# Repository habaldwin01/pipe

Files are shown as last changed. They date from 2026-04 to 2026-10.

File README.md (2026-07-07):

# Particle Imager for Plankton in the Environment

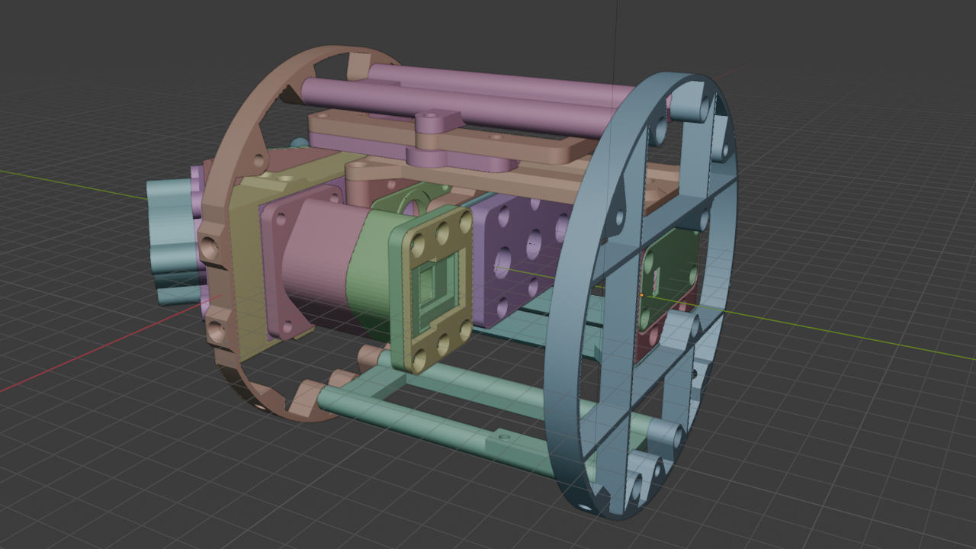
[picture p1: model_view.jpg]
View of the printable parts of PIPE in Blender


The PIPE is an almost fully 3D-printable pumped fluid microscope targeting particles in the range of 10-500 micron. As designed, it requires ***zero*** specialist components, with everything being either 3D-printable, readily avalaible to purchase on sites like eBay, or quickly made with a hacksaw and drill.

**Side-by-side comparison of the resolution of a PIPE prototype vs the IFCB:**

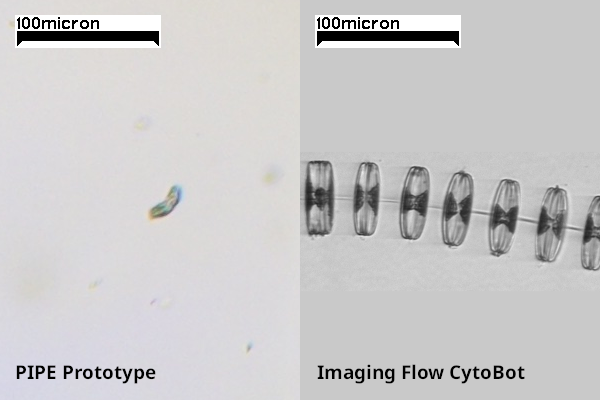
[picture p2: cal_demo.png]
Example side-by-side comparison of the resolution of the PIPE vs the IFCB


## Licence and acknowledgements

This project would not have been possible without the work of the team at FairScope, creators of the [PlanktoScope](https://github.com/fairscope/PlanktoScope). The PIPE is heavily inspired by the PlanktoScope, and borrows some pieces of its design. All physical designs for the PIPE are therefore also CERN OHL-S V2 licensed, and you are free to adapt and re-use the designs in accordance with the licence.

## Non-printable parts required

- 2x 8mm ID, 14mm OD, 0.5mm thick washer (stainless steel preferably, although copper crush washers also work)
- ~50 M3 16mm countersunk hex bolts
- ~50 M3 4-6mm brass threaded inserts
- 2x 6x2mm o-ring
- 1x 12x2mm o-ring
- 2x 10x2mm o-ring
- 1x 38x3mm o-ring
- 4x Female Luer Lock to 2.4mm silicone tube ID fittings
- 4x Male Luer Lock to 2.4mm silicone tube ID fittings
- About 1m 2mm ID silicone tube
- Standard microscope slide (75x26x1mm)
- 2x 25mm diameter CO2 laser cutter Molybdenum mirrors
- Piece (75x26x2mm) of clear acrylic or polycarbonate with two 5mm holes drilled 50mm apart, centered
- Single segment (10-30mm) of 12v white LED strip
- Peristaltic pump with 2mm silicone tube fittings
- Standard optical microscope condenser
- Standard Plan 10/0.25 Objective with RMS thread (must NOT be infinity-corrected)
- Raspberry Pi 3 B+ (or Later) and power supply
- Raspberry Pi Camera Module 3
- 12V 2A power supply
- 2x step-down DC-DC converters 12V input 5V 2A(minimum) output

## Notes on printing

All components have been printed successfully on a stock Creality Ender 3. For most pieces, the default print settings are 0.4mm layer heights with the "SUPERDRAFT" speed preset in Prusa Slicer. The only exceptions are:

- slide/optical_stage_slide_oring_guide
- optical_stage/objective_mount

These parts in particular were printed with 0.2mm layer heights on the "NORMAL" preset.

Tolerances are built in to most designs, and will be suitable for most consumer 3D printers, but if you need to change them, look for a variable called "slop_adjust" near the top of the OpenSCAD file. This is used to set the gap between various surfaces that are meant to connect or brush past each other.

### Photo of an early prototype of the PIPE

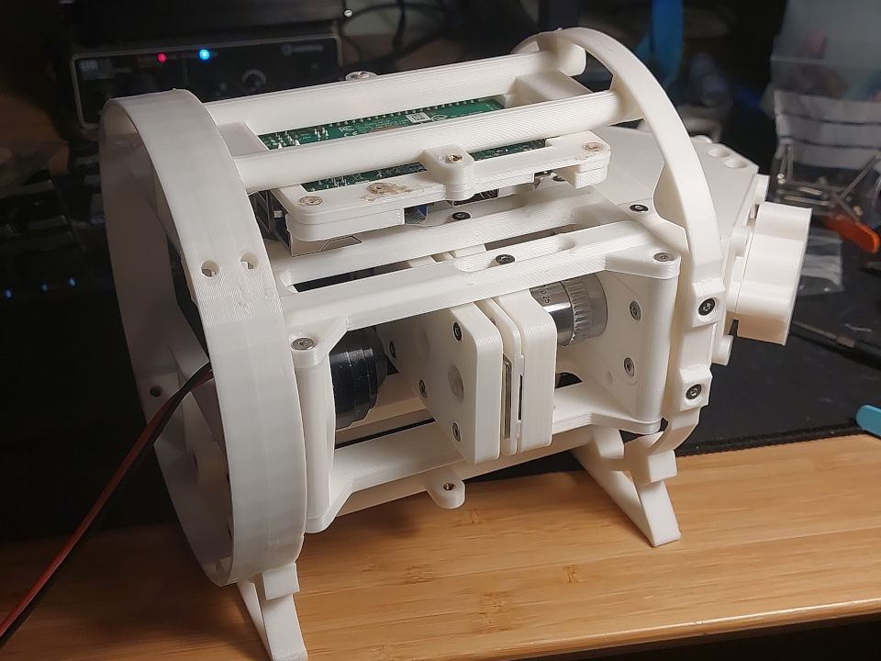
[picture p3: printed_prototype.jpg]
Early prototype of the PIPE


## Why is it called PIPE?

Because it fits in one! The entire design is built to fit in a 150mm ID pipe so it can be sealed within a pressure housing. While there aren't designs for a pressure housing included here, 150mm was chosen as it's also relatively easy to find [150mm ID PVC ducting](https://www.screwfix.com/p/manrose-150mm-round-ducting-1m/207gy). If you're not in need of serious depth rating, this will do the job of keeping the device dry.

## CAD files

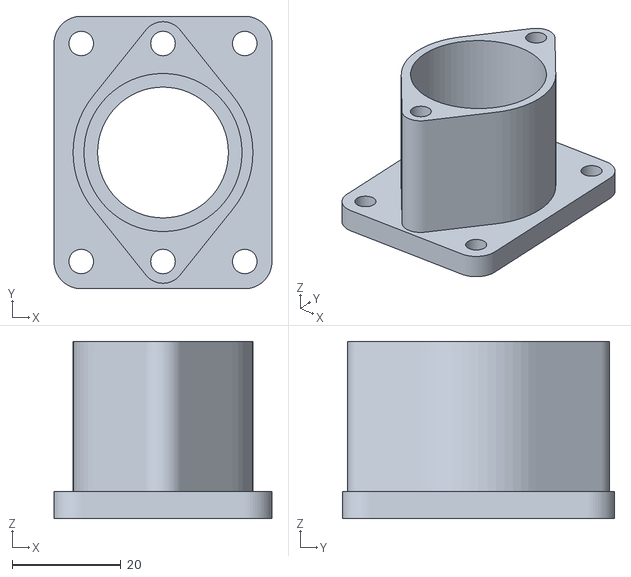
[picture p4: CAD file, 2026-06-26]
models/camera_stage/eyepiece_mount_main.stl
40.0 x 50.0 x 32.5

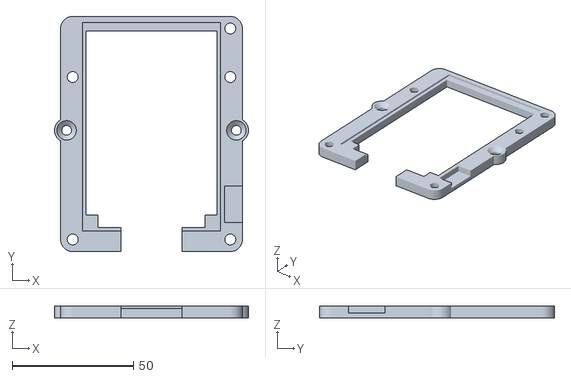
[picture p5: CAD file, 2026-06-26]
models/electronics/rpi_mount/rpi_mount_main.stl
80.0 x 97.0 x 5.00

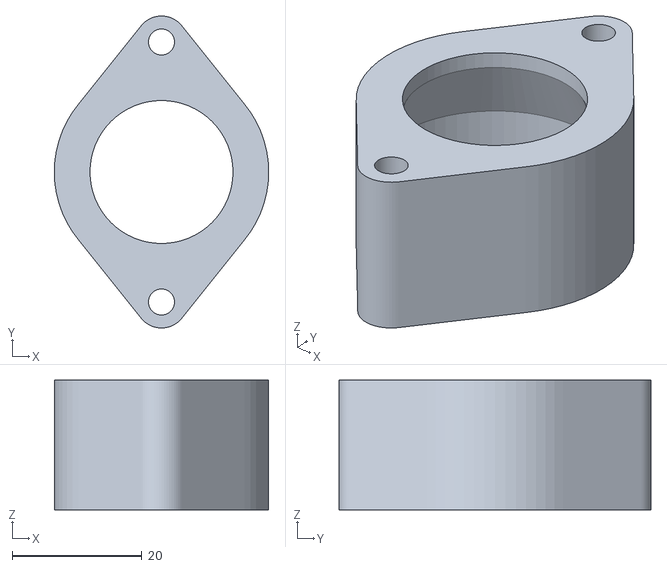
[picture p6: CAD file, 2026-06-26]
models/camera_stage/eyepiece_mount_spacer.stl
33.0 x 48.0 x 20.0

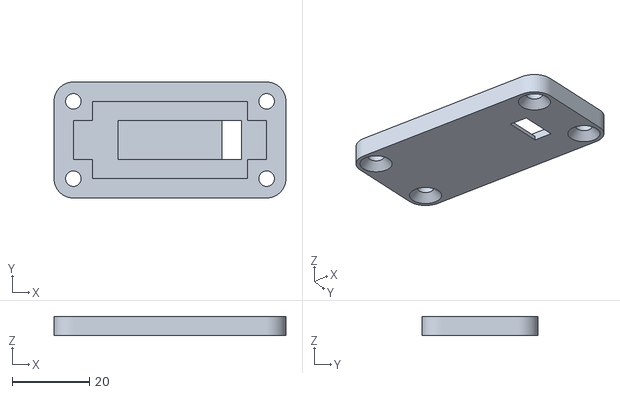
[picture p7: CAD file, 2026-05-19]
models/electronics/lamp_mount/lamp_mount.stl
60.0 x 30.0 x 5.00

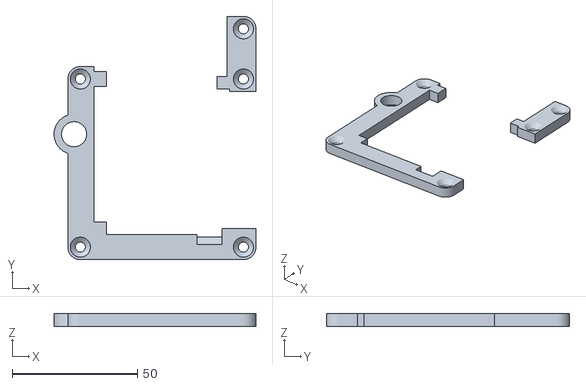
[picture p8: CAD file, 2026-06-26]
models/electronics/rpi_mount/rpi_mount_clamp.stl
80.5 x 97.0 x 5.00

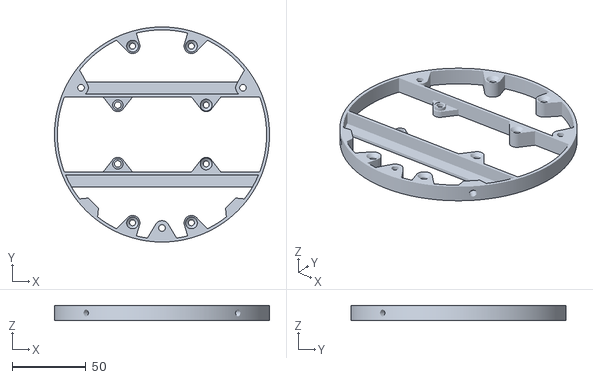
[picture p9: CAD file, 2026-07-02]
models/frame/front_frame.stl
146.0 x 146.0 x 10.0

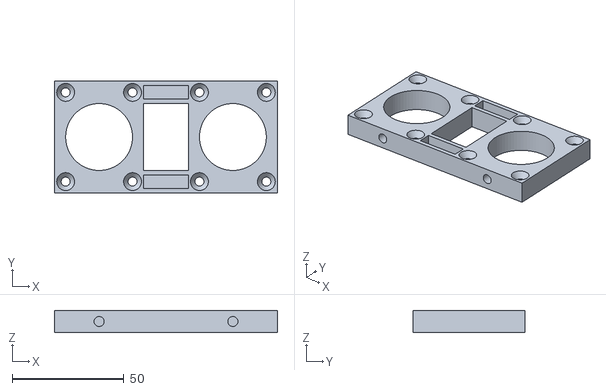
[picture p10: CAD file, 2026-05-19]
models/mirror_stage/mirror_stage_flange_plate.stl
100.0 x 50.0 x 10.0

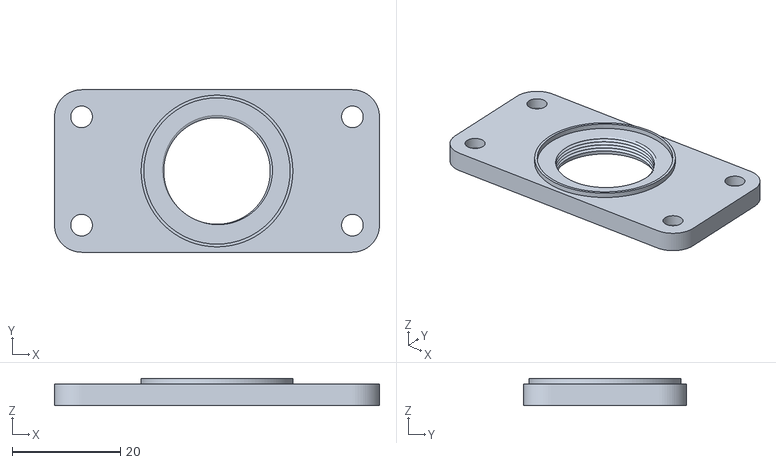
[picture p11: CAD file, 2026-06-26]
models/optical_stage/objective_mount.stl
60.0 x 30.0 x 5.00

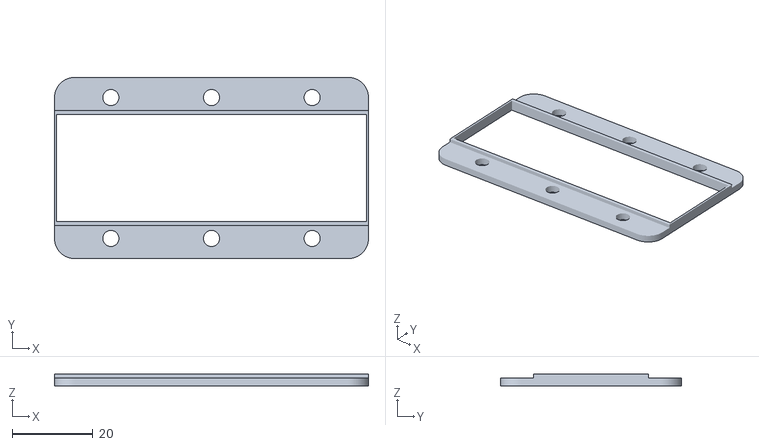
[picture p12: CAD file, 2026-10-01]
models/slide/optical_stage_slide_back_guide.stl
78.0 x 45.0 x 3.00

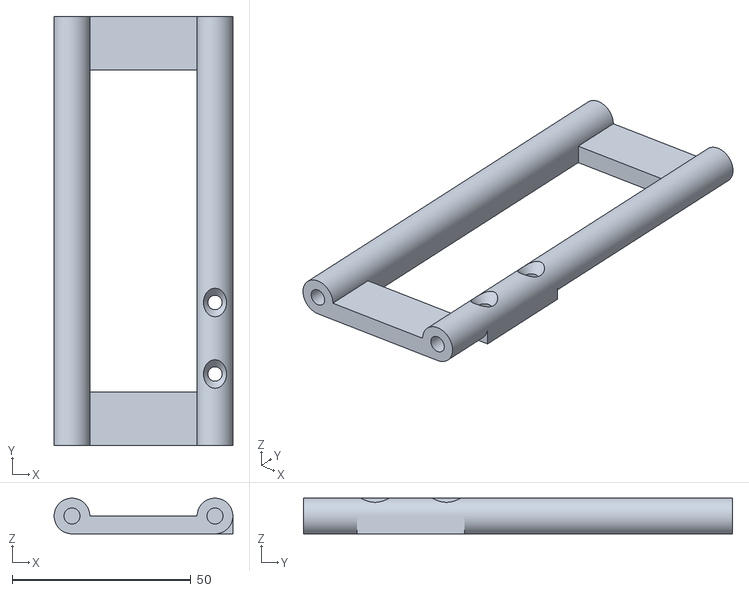
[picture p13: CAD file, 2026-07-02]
models/frame/bottom_frame.stl
50.0 x 120.0 x 10.00

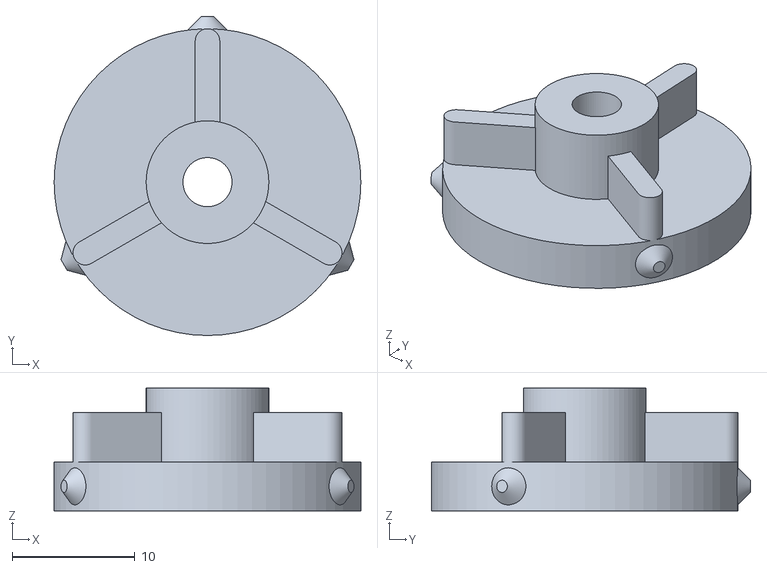
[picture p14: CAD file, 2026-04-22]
models/mirror_stage/cap_lid.stl
25.0 x 26.0 x 10.0

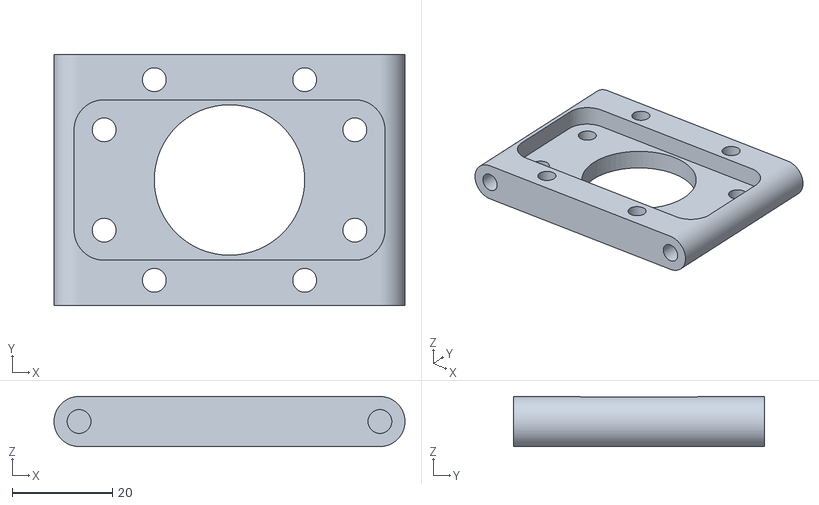
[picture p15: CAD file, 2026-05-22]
models/optical_stage/optical_cage_objective_side.stl
70.0 x 50.0 x 10.0

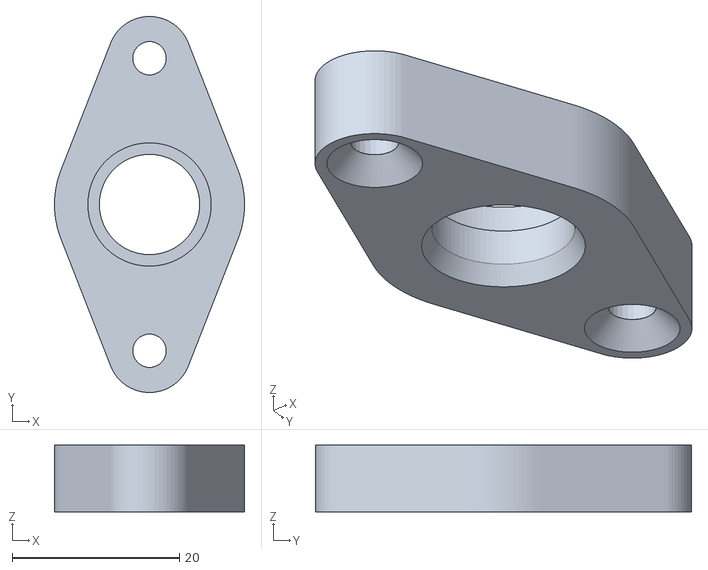
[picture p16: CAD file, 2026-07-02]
models/slide/optical_stage_slide_luer_clamp.stl
22.7 x 45.0 x 8.00

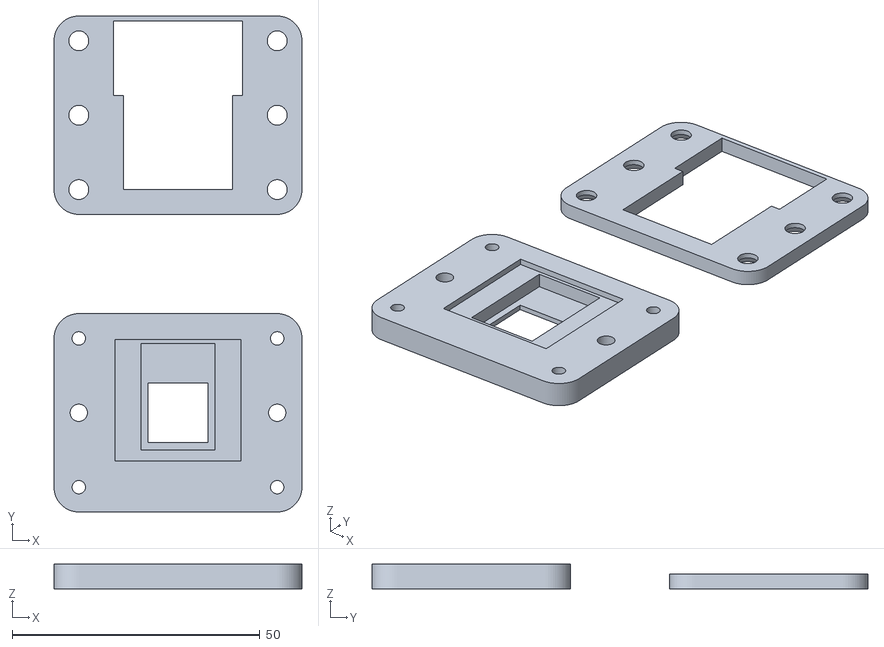
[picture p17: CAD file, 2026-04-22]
models/electronics/rpi_mount/rpi_camera_module_mount.stl
50.0 x 100.0 x 5.00

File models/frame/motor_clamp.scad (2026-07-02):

$fa=1;
$fs=0.5;

frame_length = 120;

sh_through = 4;
sh_countersink = 3;
sh_thread = 4.5; // 2.7 for tapping, 4.5 for brass insert

motor_dia = 32;

shell_thickness = 2;

motor_center_height = 40;

module countersink_cyl() {
    hull () {
        translate([0,0,-30])cylinder(1, (sh_countersink-1) + (sh_through/2), (sh_countersink-1) + (sh_through/2));
        translate([0,0,-1])cylinder(sh_countersink, (sh_countersink-1) + (sh_through/2), sh_through/2);
    }

    translate([0,0,0])cylinder(30, sh_through/2, sh_through/2);
}

difference() {
    union(){
        cylinder(10,motor_dia/2 + shell_thickness,motor_dia/2 + shell_thickness);
        translate([0,-10/2 + 10,0])cube([motor_center_height,10,10]);
        translate([0,-10/2 - 10,0])cube([motor_center_height,10,10]);
        translate([motor_center_height-shell_thickness,-30/2,0])cube([shell_thickness,30,10]);
        
        difference(){
            translate([-motor_dia/2-10,-2.5-5,0])cube([10,5,10]);
            translate([-motor_dia/2-5,-7,5])rotate([-90,0,0])countersink_cyl();
        }
        difference(){
            translate([-motor_dia/2-10,2.5,0])cube([10,5,10]);
            translate([-motor_dia/2-5,0,5])rotate([-90,0,0])cylinder(50,sh_thread/2,sh_thread/2);
        }
        
    }

    translate([0,0,-1])cylinder(12,motor_dia/2,motor_dia/2);
    
    translate([-50,-2.5,-1])cube([50,5,12]);
    
    translate([motor_center_height-20,-(20/2),5])rotate([0,90,0])cylinder(50,sh_thread/2,sh_thread/2);
    translate([motor_center_height-20,+(20/2),5])rotate([0,90,0])cylinder(50,sh_thread/2,sh_thread/2);
}

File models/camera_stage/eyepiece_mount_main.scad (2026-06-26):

use <threadlib/threadlib.scad>
$fn=64;


sh_through = 4;
sh_countersink = 3;
sh_thread = 4.5; // 2.7 for tapping, 4.5 for brass insert


shoulder_size = 2;
thickness = 5;
wall_thickness = 2;

through_casing_radius = sh_through/2 + wall_thickness;

mounting_holes_height = 30;
mounting_holes_width = 40;

difference() {
    union() {
        hull() {
            translate([0,-20,0])cylinder(31.5+shoulder_size-1, through_casing_radius,through_casing_radius);
            translate([0,0,0])cylinder(31.5+shoulder_size-1, 29/2 + 2, 29/2 + 2);
            translate([0,20,0])cylinder(31.5+shoulder_size-1, through_casing_radius,through_casing_radius);
        }
        hull() {
            translate([-mounting_holes_height/2,mounting_holes_width/2,0])cylinder(thickness,5,5);
            translate([mounting_holes_height/2,mounting_holes_width/2,0])cylinder(thickness,5,5);
            translate([-mounting_holes_height/2,-mounting_holes_width/2,0])cylinder(thickness,5,5);
            translate([mounting_holes_height/2,-mounting_holes_width/2,0])cylinder(thickness,5,5);
        }
    }
    
    translate([0,0,shoulder_size])cylinder(31.5+1,29/2,29/2);
    translate([0,0,-1])cylinder(10,24/2,24/2);
    
    
    translate([0,-20,-1])cylinder(50, sh_thread/2, sh_thread/2);
    translate([0,20,-1])cylinder(50, sh_thread/2, sh_thread/2);
    
    translate([-mounting_holes_height/2,mounting_holes_width/2,-1])cylinder(15, sh_thread/2, sh_thread/2);
    translate([mounting_holes_height/2,mounting_holes_width/2,-1])cylinder(15, sh_thread/2, sh_thread/2);
    translate([-mounting_holes_height/2,-mounting_holes_width/2,-1])cylinder(15, sh_thread/2, sh_thread/2);
    translate([mounting_holes_height/2,-mounting_holes_width/2,-1])cylinder(15, sh_thread/2, sh_thread/2);
}

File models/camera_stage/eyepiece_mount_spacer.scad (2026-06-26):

use <threadlib/threadlib.scad>
$fn=64;


sh_through = 4;
sh_countersink = 3;
sh_thread = 4.5; // 2.7 for tapping, 4.5 for brass insert

shoulder_size = 2;
thickness = 10;
wall_thickness = 2;

through_casing_radius = sh_through/2 + wall_thickness;

mounting_holes_height = 30;
mounting_holes_width = 40;

eyepiece_distance = 20;

difference() {
    union() {
        hull() {
            translate([0,-20,0])cylinder(eyepiece_distance, through_casing_radius,through_casing_radius);
            translate([0,0,0])cylinder(eyepiece_distance, 29/2 + 2, 29/2 + 2);
            translate([0,20,0])cylinder(eyepiece_distance, through_casing_radius,through_casing_radius);
        }
    }
    
    translate([0,0,-shoulder_size-8])cylinder(eyepiece_distance,29/2,29/2);
    translate([0,0,eyepiece_distance-shoulder_size-8])cylinder(8,29/2,22/2);
    translate([0,0,-1])cylinder(eyepiece_distance+2,22/2,22/2);
    
    translate([0,-20,-1])cylinder(50, sh_through/2, sh_through/2);
    translate([0,20,-1])cylinder(50, sh_through/2, sh_through/2);
}

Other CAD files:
models/frame/motor_clamp.stl
models/mirror_stage/static_mirror_bracket.stl
models/optical_stage/optical_cage_side.stl
models/slide/optical_stage_slide_centre_clamp.stl
models/frame/back_frame.scad
models/electronics/lamp_mount/lamp_mount.scad
models/electronics/rpi_mount/rpi_camera_module_mount.scad
models/electronics/rpi_mount/rpi_mount.scad
models/electronics/rpi_mount/rpi_mount_clamp.scad
models/electronics/rpi_mount/rpi_mount_main.scad
models/frame/back_frame.stl
models/frame/bottom_frame.scad
models/frame/front_frame.scad
models/frame/mirror_flange_carrier.scad
models/frame/mirror_flange_carrier.stl
models/frame/open_frame_feet.scad
models/frame/open_frame_feet.stl
models/frame/top_frame.scad
models/frame/top_frame.stl
models/mirror_stage/cap_base.scad
models/mirror_stage/cap_base.stl
models/mirror_stage/cap_lid.scad
models/mirror_stage/mirror_stage_body.scad
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

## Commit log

2026-04-22 Initial work
    [cap_base.scad, cap_base.stl, cap_lid.scad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]
2026-05-19 General design refinements
    [condenser_side_frame.scad, lamp_mount.scad, lamp_mount.stl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]
2026-05-20 Improvements to frame
    [back_frame.scad, condenser_side_frame.scad, front_frame.scad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]
2026-05-22 General improvements and frame design
    [back_frame.stl, bottom_frame.scad, bottom_frame.stl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]
2026-05-24 Updates to slide design
    [objective_mount.scad, objective_mount.stl, optical_cage_objective_side.scad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]
2026-06-26 Design optimisations and more clearance for slide
    [eyepiece_mount_main.scad, eyepiece_mount_main.stl, eyepiece_mount_spacer.scad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]
2026-06-30 Significant frame improvements
    [back_frame.scad, back_frame.stl, bottom_frame.scad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]
2026-07-02 Further major refinements to frame, and adding notes on printing
    [back_frame.scad, back_frame.stl, bottom_frame.scad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]
2026-07-02 Improved slide design and adding clamp for pump
    [back_frame.scad, bottom_frame.scad, bottom_frame.stl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]
2026-07-07 Update README with new prototype image and details
    Removed early prototype image and description, added a new photo of an early prototype, and clarified the PIPE's design purpose.
2026-10-01 Adding guide for back cover
    [optical_stage_slide_back_guide.scad, optical_stage_slide_back_guide.stl]
